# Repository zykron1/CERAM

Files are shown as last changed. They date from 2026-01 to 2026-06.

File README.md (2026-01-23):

# CERAM
CERAM - Cost-Effective Rocket Aviation Module
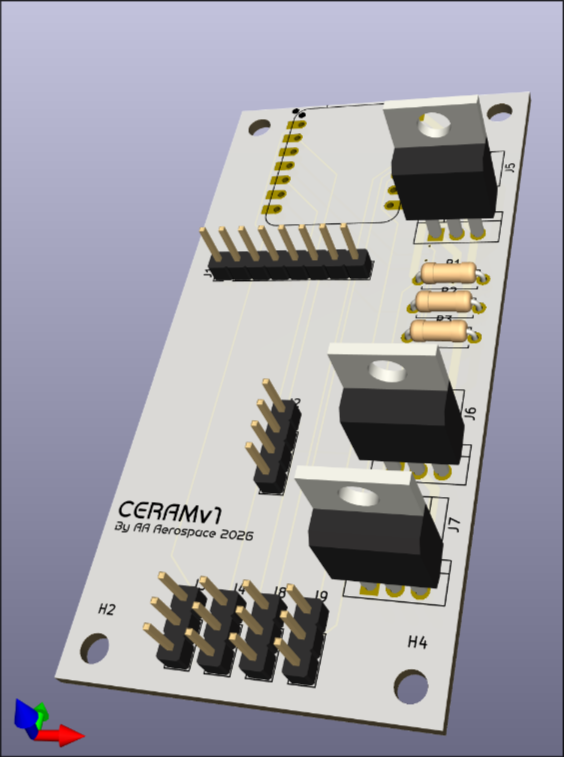
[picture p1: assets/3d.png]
3d view of pcb


## Why
Most rocket flight computers are made of SMD components and are designed to be made at scale by automated pick and place machines, but these methods are extremely expensive if you aren't manufacturing at scale.

## Schematic
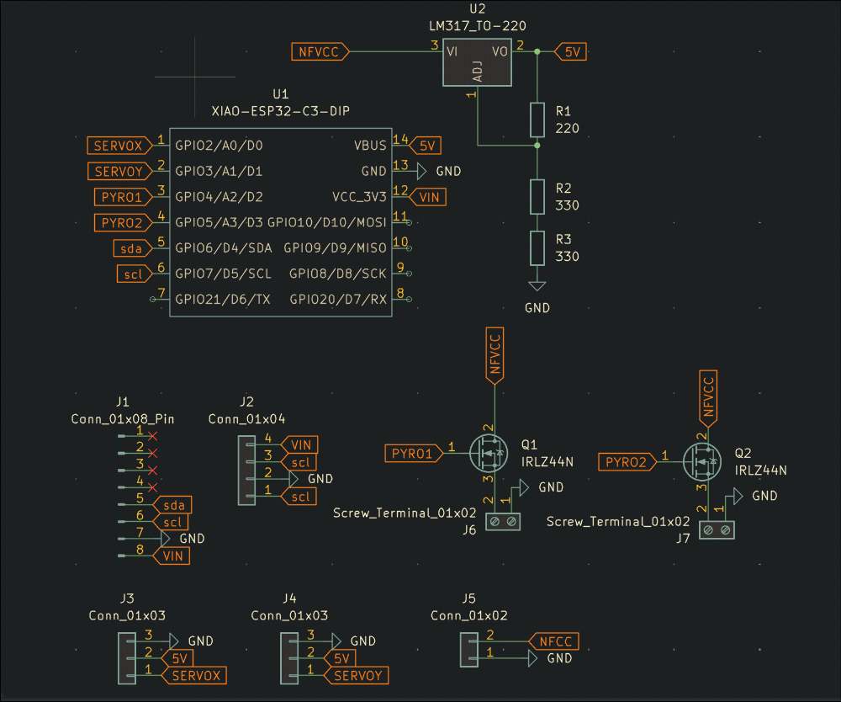
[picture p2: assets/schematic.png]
Schematic


## PCB
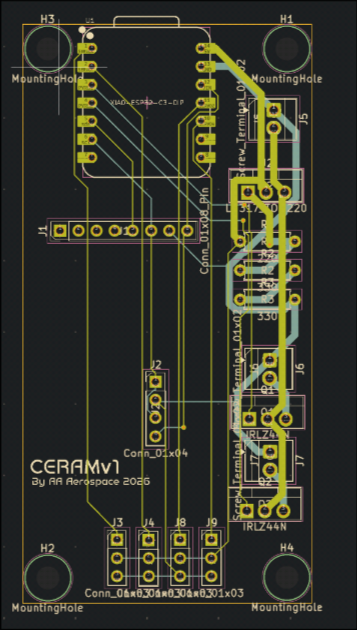
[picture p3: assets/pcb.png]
PCB


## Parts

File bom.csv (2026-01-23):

Part | Link | Cost
XIAO-ESP32-C3-DIP | https://www.aliexpress.us/item/3256809899117724.html | $8.18
BNO-055 | https://www.aliexpress.us/item/3256809024597875.htm | $7.84
BMP-280 | https://www.aliexpress.us/item/3256806639452412.html | $2.64
IRZ44N MOSFET | https://www.aliexpress.us/item/2255800801798474.html | $1.97
LM317 | https://www.aliexpress.us/item/3256810187496141.html | $2.49
2.44mm Male Headers | https://www.aliexpress.us/item/2255800801798474.html | $0.99
Generic Resistor Kit | https://www.aliexpress.us/item/3256808562766775.html | $1.87
Screw Terminals | https://www.aliexpress.us/item/3256805790985088.html | $2.44
Subtotal | $28.42
Shipping | $15.15
Total | $43.57
With PCB | $50.69

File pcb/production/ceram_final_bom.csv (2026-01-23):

Designator | Footprint | Quantity | Value | LCSC Part #
J1 | PinHeader_1x08_P2.54mm_Vertical | 1 | Conn_01x08_Pin
J2 | PinHeader_1x04_P2.54mm_Vertical | 1 | Conn_01x04
J3, J4, J8, J9 | PinHeader_1x03_P2.54mm_Vertical | 4 | Conn_01x03
J5, J6, J7 | TerminalBlock_Xinya_XY308-2.54-2P_1x02_P2.54mm_Horizontal | 3 | Screw_Terminal_01x02
Q1, Q2 | TO-220-3_Vertical | 2 | IRLZ44N
R1 | R_Axial_DIN0207_L6.3mm_D2.5mm_P7.62mm_Horizontal | 1 | 220
R2, R3 | R_Axial_DIN0207_L6.3mm_D2.5mm_P7.62mm_Horizontal | 2 | 330
U1 | XIAO-ESP32C3-DIP | 1 | XIAO-ESP32-C3-DIP
U2 | TO-220-3_Vertical | 1 | LM317_TO-220

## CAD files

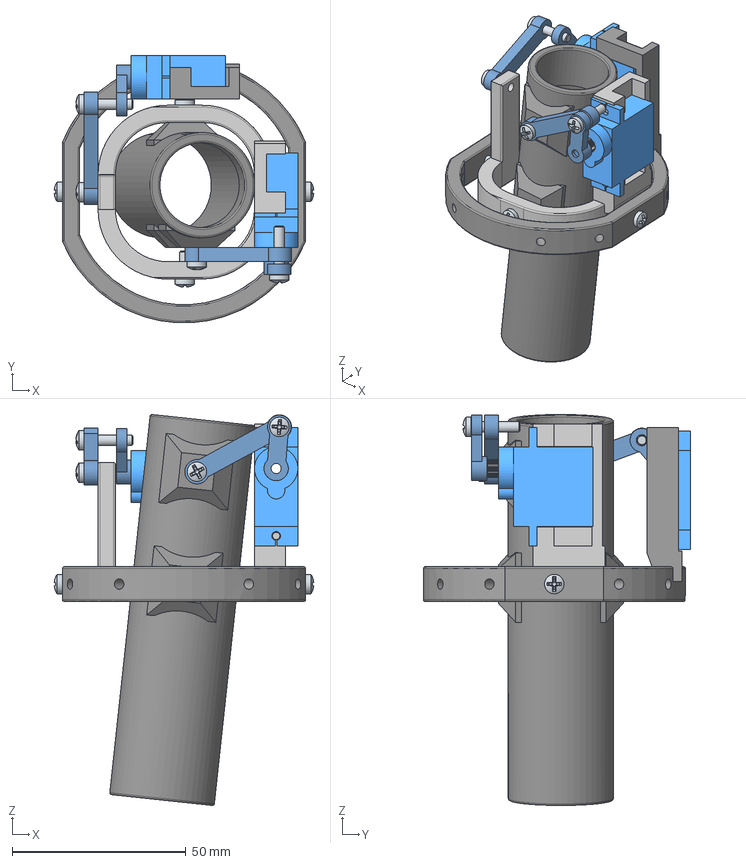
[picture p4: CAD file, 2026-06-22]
cad/TVCSubassembly.step
74.7 x 76.9 x 112.5 mm
PH Pan head screw M3x0.50 x 14 x 4
PH Pan head screw M3x0.50 x 8 x 2
PushRod x 2
MotorShroud29mm
ServoHorn x 2
OuterGimbal
InnerGimbal
SG90 x 2
PH Pan head screw M3x0.50 x 6 x 2

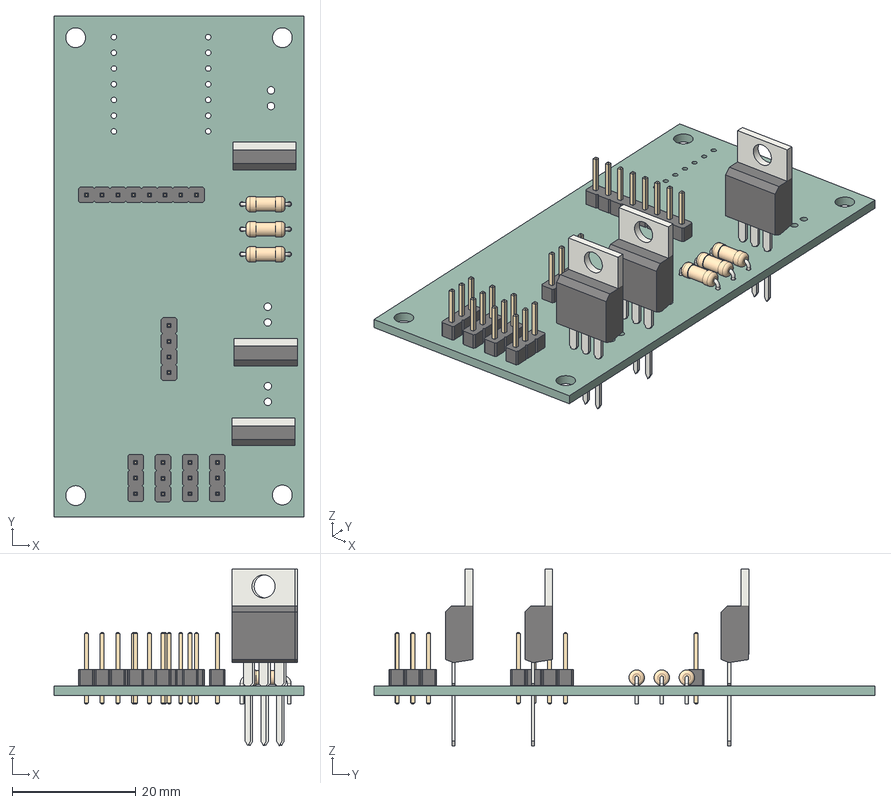
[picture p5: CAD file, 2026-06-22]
pcb/pcb.step
40.4 x 80.9 x 28.5 mm
PinHeader_1x08_P2.54mm_Vertical
PinHeader_1x04_P2.54mm_Vertical
R_Axial_DIN0207_L6.3mm_D2.5mm_P7.62mm_Horizontal x 3
PinHeader_1x03_P2.54mm_Vertical x 4
TO-220-3_Vertical x 3
CERAM_PCB

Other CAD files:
pcb/.step

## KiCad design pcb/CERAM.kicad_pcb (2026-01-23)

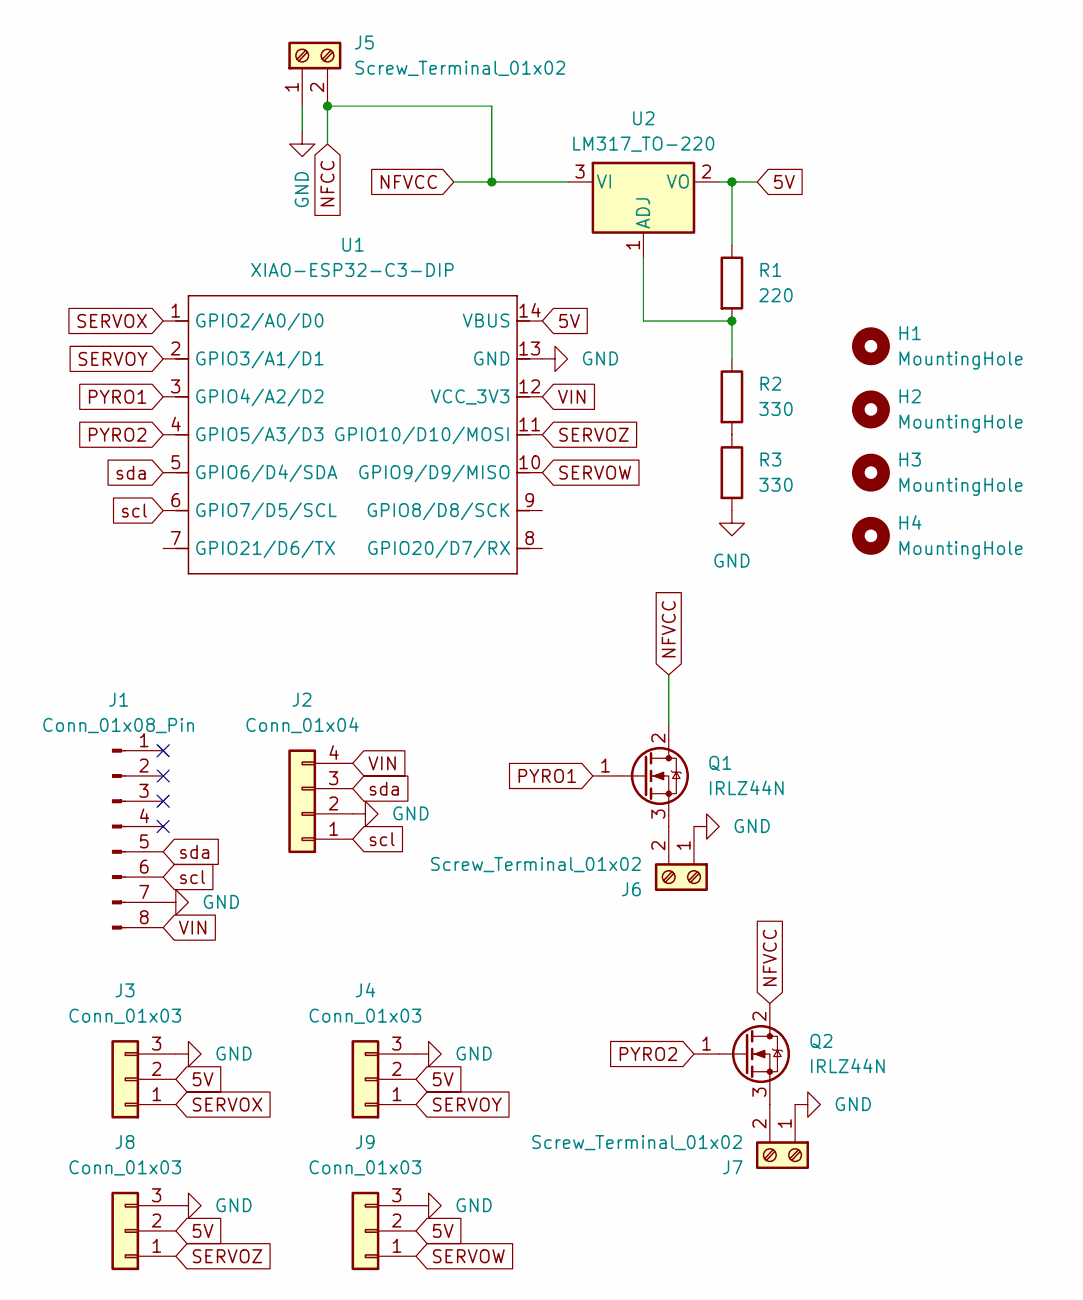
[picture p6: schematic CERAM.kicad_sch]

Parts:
H1, H2, H3, H4: MountingHole; MountingHole_3.2mm_M3
J1: Conn_01x08_Pin; PinHeader_1x08_P2.54mm_Vertical
J2: Conn_01x04; PinHeader_1x04_P2.54mm_Vertical
J3, J4, J8, J9: Conn_01x03; PinHeader_1x03_P2.54mm_Vertical
J5, J6, J7: Screw_Terminal_01x02; TerminalBlock_Xinya_XY308-2.54-2P_1x02_P2.54mm_Horizontal
Q1, Q2: IRLZ44N; TO-220-3_Vertical
R1: 220; R_Axial_DIN0207_L6.3mm_D2.5mm_P7.62mm_Horizontal
R2, R3: 330; R_Axial_DIN0207_L6.3mm_D2.5mm_P7.62mm_Horizontal
U1: XIAO-ESP32-C3-DIP; XIAO-ESP32C3-DIP
U2: LM317_TO-220; TO-220-3_Vertical

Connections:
5V: J3.2, J4.2, J8.2, J9.2, R1.1, U1.14 (VBUS), U2.2 (VO)
GND: J1.7, J2.2, J3.3, J4.3, J5.1, J6.1, J7.1, J8.3, J9.3, R3.2, U1.13 (GND)
NFCC: J5.2, Q1.2 (D), Q2.2 (D), U2.3 (VI)
unnamed: J6.2, Q1.3 (S)
unnamed: J7.2, Q2.3 (S)
unnamed: R2.2, R3.1
unnamed: R1.2, R2.1, U2.1 (ADJ)
PYRO1: Q1.1 (G), U1.3 (GPIO4/A2/D2)
PYRO2: Q2.1 (G), U1.4 (GPIO5/A3/D3)
SERVOW: J9.1, U1.10 (GPIO9/D9/MISO)
SERVOX: J3.1, U1.1 (GPIO2/A0/D0)
SERVOY: J4.1, U1.2 (GPIO3/A1/D1)
SERVOZ: J8.1, U1.11 (GPIO10/D10/MOSI)
VIN: J1.8, J2.4, U1.12 (VCC_3V3)
scl: J1.6, J2.1, U1.6 (GPIO7/D5/SCL)
sda: J1.5, J2.3, U1.5 (GPIO6/D4/SDA)

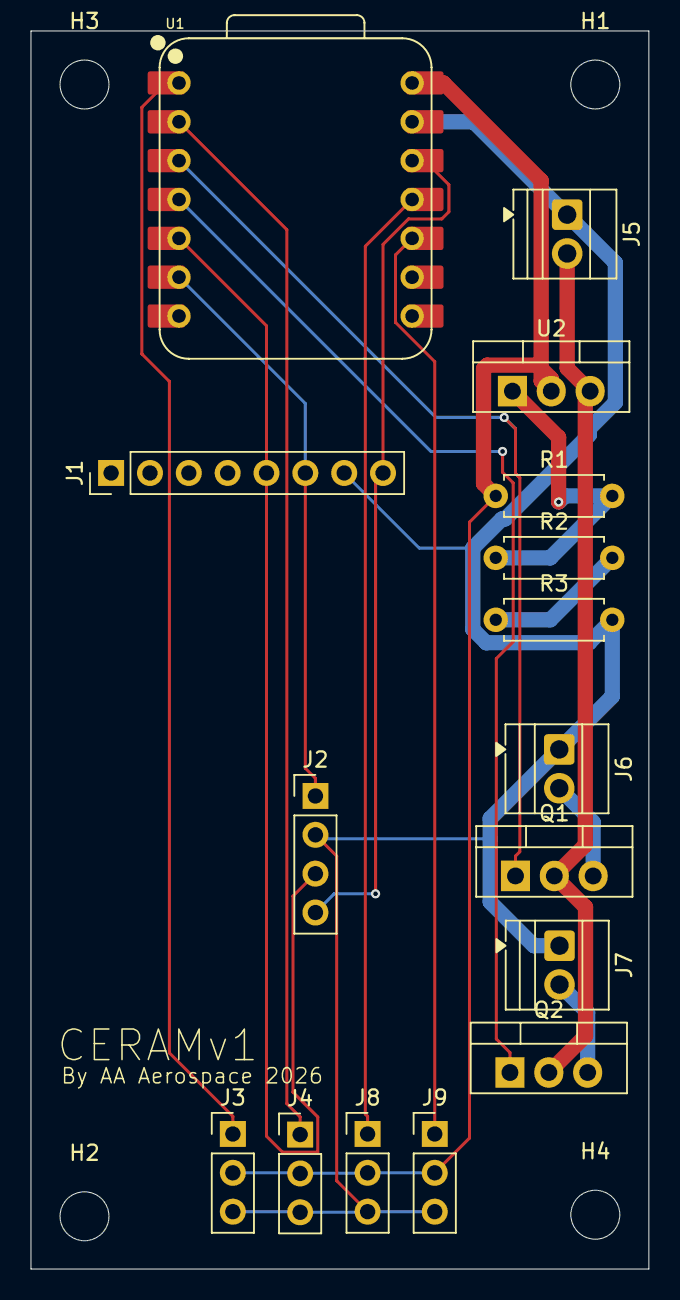
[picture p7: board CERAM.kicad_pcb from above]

Board: 2 copper layers, 40.4 x 80.9 mm, 20 parts (0 on the bottom side), 16 nets.

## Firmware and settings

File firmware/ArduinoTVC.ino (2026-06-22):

#include <Wire.h>
#include "MPU6050.h"
#include "StateEstimator.h"
#include "SG90.h"
#include "States.h"
#include "BMP180.h"
#include "PID.h"
#include "TVCMount.h"
#include "esp32-hal-gpio.h"

#define MOTOR_BURN 395.5f
#define DEPLOY_TIMER 5 // If baro fails
#define APOGEE_DROPOUT 2 // Meters to fall before deployment

MPU6050 imu;
BMP180 baro;

SG90 xservo;
SG90 yservo;
TVCMount mount(xservo, yservo);

PID xPID(0.4, 0, 0.2);
PID yPID(0.4, 0, 0.2);

MPU6050Data i;
BMP180Data b;
float apogee;

StateEstimator state;
States stage = PAD;

uint32_t startTime = 0;
uint32_t lastTime = 0;

void setup() {
	Serial.begin(115200);
	Wire.begin(6, 7);

	imu.init(0x68);
	baro.init(0x77);

	delay(100);
	imu.calibrate(500, 10); // 500 samples @ 10ms
	Serial.printf("{%f, %f, %f} \n", imu.drift.gx, imu.drift.gy, imu.drift.gz);

	xservo.initServo(9); // INNER
	yservo.initServo(2); // OUTER
	pinMode(4, OUTPUT);

	startTime = micros();
	lastTime = startTime;
}

const uint32_t PERIOD_US = 10000; 
void loop() {
	switch (stage) {
		case PAD:
		{
			// Wait for launch, poll accelerometers, do not integrate state
			i = imu.getData();
			b = baro.getData();
			Serial.printf("AWAITING LAUNCH %f m/s2 BARO ALT: %f\n", i.ax, b.altitude);
			if (i.ax > 1.0f) { // 1 m/s threshold
				Serial.printf("Staging to TVC \n");
				stage = next(stage);
				startTime = micros();
				lastTime = micros();
			}
			break;
		}
		case POWERED_FLIGHT:
		{
			uint32_t now = micros();
			float t = (now - startTime) / 1000000.0f;

			// Stage after motor burnout
			if (t >= MOTOR_BURN) {
				state.resetVelocity();
				stage = next(stage);
				startTime = micros(); 
				lastTime = micros();
				b = baro.getData();
				apogee = b.altitude;
				Serial.println("Staging to coast phase");
				break;
			}
			if (now - lastTime >= PERIOD_US) {
				float actual_ms = (now - lastTime) / 1000.0f;
				lastTime += PERIOD_US;

				i = imu.getData();

				state.updateState({i.gx, i.gy, i.gz}, b.altitude, actual_ms); // dont poll alt during flight

				Orientation rocket = state.getOrientation() * RAD_TO_DEG;
				float xAngle = rocket.y;
				float yAngle = -rocket.z; // due to mpu mounting

				int xCommand = (int)xPID.updateLoop(xAngle, 0, 0.01); // state=xAngle, setpoint 0, dt = 10ms
				int yCommand = (int)yPID.updateLoop(yAngle, 0, 0.01); // state=yAngle, setpoint 0, dt = 10ms
				xCommand = constrain(xCommand, -5, 5);
				yCommand = constrain(yCommand, -5, 5);


				mount.moveMount(xCommand, yCommand);

				Serial.printf("TVC: t=%f, dt=%f ms, roll=%f, x=%f, y=%f command = %d, %d \n",
						(micros() - startTime) / 1000000.0f,
						actual_ms,
						rocket.x, xAngle, yAngle, xCommand, yCommand);

			}
			break;
		}
		case COAST:
		{
			uint32_t now = micros();
			float t = (now - startTime) / 1000000.0f;

			if (now - lastTime >= PERIOD_US) {
				float actual_ms = (now - lastTime) / 1000.0f;
				lastTime += PERIOD_US;

				i = imu.getData();
				b = baro.getData();

				state.updateState({i.gx, i.gy, i.gz}, b.altitude, actual_ms);
				Serial.printf("COASTING: %f m \n", b.altitude);

				if (b.altitude > apogee) {
					Serial.printf("NEW APOGEE: %f m\n", b.altitude);
					apogee = b.altitude;
				}

				if (b.altitude < apogee - APOGEE_DROPOUT || t > DEPLOY_TIMER) {
					Serial.printf("Staging to parachute deployment @ %f m t = %f s\n", b.altitude, t);
					stage = next(stage);
					startTime = micros();
					lastTime = micros();
				}
			}
			break;
		}
		case DEPLOY:
		{
			// Set explosive channels to high
			delay(20*1000);
			Serial.printf("FIRING! \n");
			// Parachute should hopefully deploy..
			digitalWrite(4, HIGH); // PYRO1 HIGH
			break;
		}
	}
}

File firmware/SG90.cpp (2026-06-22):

#include "SG90.h"

void SG90::initServo(int p) {
	servo.setPeriodHertz(50);
	bool ok = servo.attach(p, SERVO_MIN_US, SERVO_MAX_US);
	Serial.printf("Servo attach on pin %d: %s\n", p, ok ? "OK" : "FAILED");
	delay(500);
}

void SG90::setPosition(int angle) {
	angle = constrain(angle, 0, 180);
	servo.write(angle);
}

void SG90::smoothPosition(int angle) {
	angle = constrain(angle, 0, 180);
	int current = servo.read();
	int step = (angle > current) ? 1 : -1;
	for (int pos = current; pos != angle; pos += step) {
		servo.write(pos);
		delay(SWEEP_DELAY);
	}
	servo.write(angle);
}

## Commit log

2026-01-23 rough initial commit
    [CERAM.kicad_pcb, CERAM.kicad_sch]
2026-01-23 jlcpcb outputs
    [ceram_final_bom.csv, ceram_final_designators.csv, ceram_final_positions.csv]
2026-01-23 updated bom with final totals
    [bom.csv]
2026-06-22 accurate firmware
    [output.csv, partitions.csv]
2026-06-22 forgot to remove build
    [partitions.csv]
